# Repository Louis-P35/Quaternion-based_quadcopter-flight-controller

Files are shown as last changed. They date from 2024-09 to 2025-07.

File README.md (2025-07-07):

# MicroFlight - a quadcopter drone flight controller

## Overview

This repository contains the source code for a quadcopter drone flight controller developed in C++ on an STM32H7 microcontroller. Various sensors and control algorithms are used to achieve stable and responsive flight.

## Demo
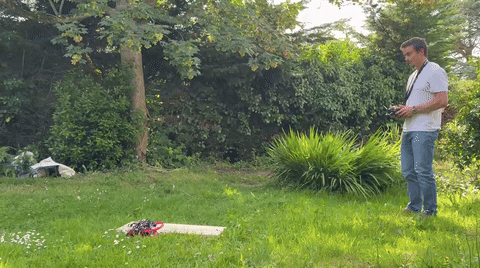
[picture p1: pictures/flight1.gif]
First flight


## Features

- **Microcontroller**: Support the STM32H7 microcontroler, running at 480 MHz.
- **High frequency loop**: IMU data acquisition and filtering at 4khz, PID rate running at 2khz.
- **IMU Sensor**: Support the ICM20948  (3-axis accelerometer, 3-axis gyroscope, and 3-axis magnetometer) IMU with SPI for fast communication.
- **Optical Flow & Lidar**: Support the MTF-01 sensor, it provide horizontal velocity and ground distance to enable position and altitude holding. Use UART with the DMA for non-blocking reading.
- **Radio Receiver**: Support PWM signals and Sbus protocol. Read the Sbus signal over UART with the DMA for non-blocking reading.
- **ESC Control**: Support 500Hz PWM generation to command the brushless motors' ESCs.
- **AHRS (Attitude Estimation)**: Use a Madgwick filter (sensor fusion) for stabilized flight mode.
- **Quaternion Calculations**: To avoid gimbal lock pitfall and enable efficient spherical rotation interpolation, quaternions are used in the entire control loop.
- **PID Controllers**: 3 PID controllers can be chained for various flight modes including stabilized, acrobatic, and position hold mode. PID coefficients can be tuned.
- **Filtering**: First order and second order low pass filter are used to filter out the noise. Cutoff frequencys can be tuned.
- **Blackbox**: Data logging asynchronousely (over UART), data logging on SD card comming soon.
- **Battery Voltage Compensation**: The motors power is constently ajusted according to the battery level. Avoiding to loose thrust at low battery.

Coming soon:
- **CLI**: Command line interface to tune radio input, PID coefficient and filters.
- **Crash Recovery**: Freefal detection and recover from it.
- **FFT and Notch filters**: Run a FFT in real time to detect noise frequency and precisely cut it with Notch filters.

## Architecture Diagram

Click on it to open it on fullscreen
<a href="docs/DroneArchitectureDiagram.drawio.svg?raw=true" target="_blank">
  Diagram overview
</a>

## Quaternions

Quaternions are used through the entire control loop.
Quaternions avoid singularities (like gimbal lock) that can occur with Euler angles, making them a robust choice for representing 3D rotations, especially in drones that can maneuver aggressively.

## AHRS (Attitude and Heading Reference System)

The AHRS fuses data from the accelerometer and gyroscope using a Madgwick filter to estimate the attitude of the quadcopter.
Madgwick filter is fast (use a gradient descent algorithm) and directly output a quaternion.

## PID Control

The project utilizes chained PID controllers to manage motor power in different flight modes.

- **Stabilized Mode**:
  - **Two Cascaded PIDs for Attitude Control**:
    - Attitude setpoint -> [PID Attitude] -> Rate setpoint -> [PID Rate] -> Torque vector -> [Mixer]
    - The attitude error is processed by a PID controller to produce an angular rate target. This target is then used as the input for another PID controller, which compute the torque vector.

- **Acrobatic Mode**:
  - **Single PID for Rate Control**:
    - Rate setpoint -> [PID Rate] -> Torque vector -> [Mixer]
    - The angular rate error is processed by a PID controller to directly compute the torque vector.

- **Position Hold Mode**:
  - **Three Cascaded PIDs for Position Control**:
    - Position Setpoint -> [PID Position] -> Attitude setpoint -> [PID Attitude] -> Rate setpoint -> [PID Rate] -> Torque vector -> [Mixer]
    - The position error is processed by a PID controller to produce an attitude target. Then the attitude error is processed by a PID controller to produce an angular rate target. Finally this rate target is used as the input for rate PID controller, which compute the torque vector.

## Mixer

The mixer is responsible for translating the desired thrust and torque commands into individual motor power levels. This is achieved through a linear transformation that accounts for the drone's geometry and motor configuration.

### X-Configuration Mixing
In the X-quad configuration, the mixer computes the motor outputs based on a target thrust (T) and torques around the three body axes (tx, ty, tz).

### Voltage Compensation
Motor commands are adjusted based on the battery voltage to maintain consistent thrust even as the battery discharges. Since thrust is proportional to the square of the voltage, a quadratic compensation is applied. A low-pass filter smooths the ADC readings to avoid abrupt changes.

### Clamping and Rescaling
To ensure motor outputs remain within the valid range [0, 1000], the mixer applies a rescaling procedure. If any motor command falls outside this range, all outputs are linearly scaled to preserve the relative distribution while ensuring no negative or overdriven values.
This ensures the drone maintains maneuverability even when operating at or near full throttle, by preserving control authority through motor power rescaling.

## Finite State Machines
- This section's documentation is work in progress

## Filtering
Filtering noise is a crucial part of a flight controler. Motors and propellers generates a lot of vibrations that propagate to the IMU that is highly sensitive to it. Silent blocks help mechanicaly reduce it but a proper filtering is still mandatory.
The graph below show the raw gyroscope data (blue line) of the pitch axis with the motors running at around 40% of their power, and the filtered data (orange line).
The filter is a second order low pass filter (biquad Butterworth) with a 75Hz cutoff frequency. 
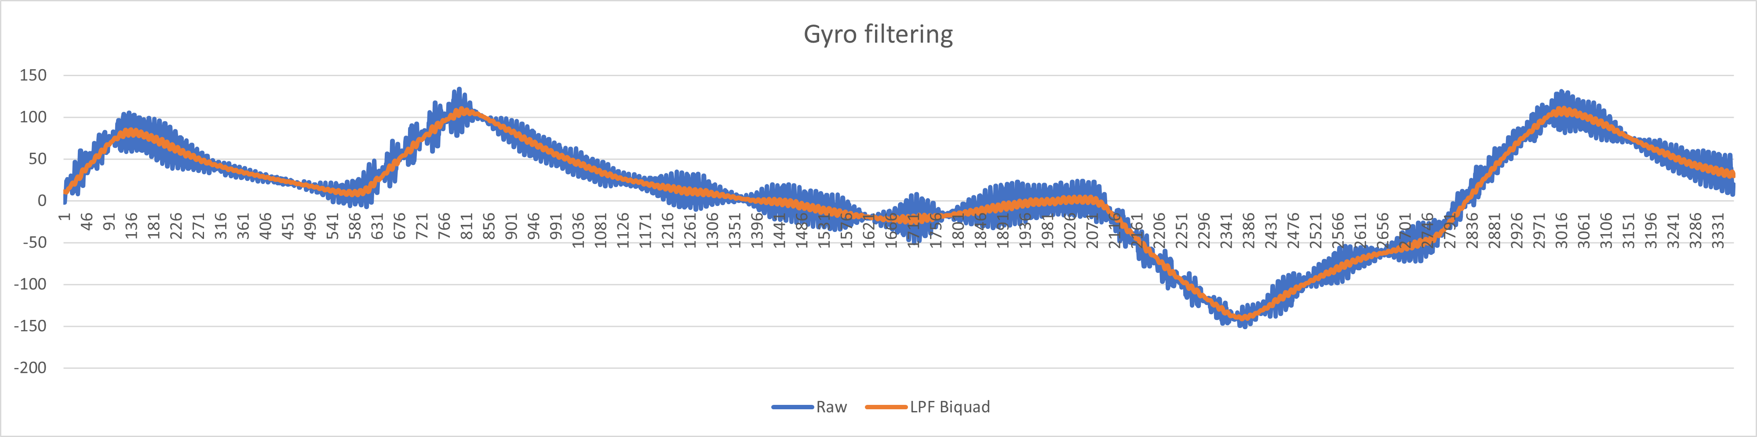
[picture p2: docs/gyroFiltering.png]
Gyro signal


The two graphs below are the fast Fourier transform (FFT) of the gyroscope data of the pitch axis with the motors at 40% of power. On the left the FFT of the raw unfiltered data is shown, on the right the FFT of the filtered data.
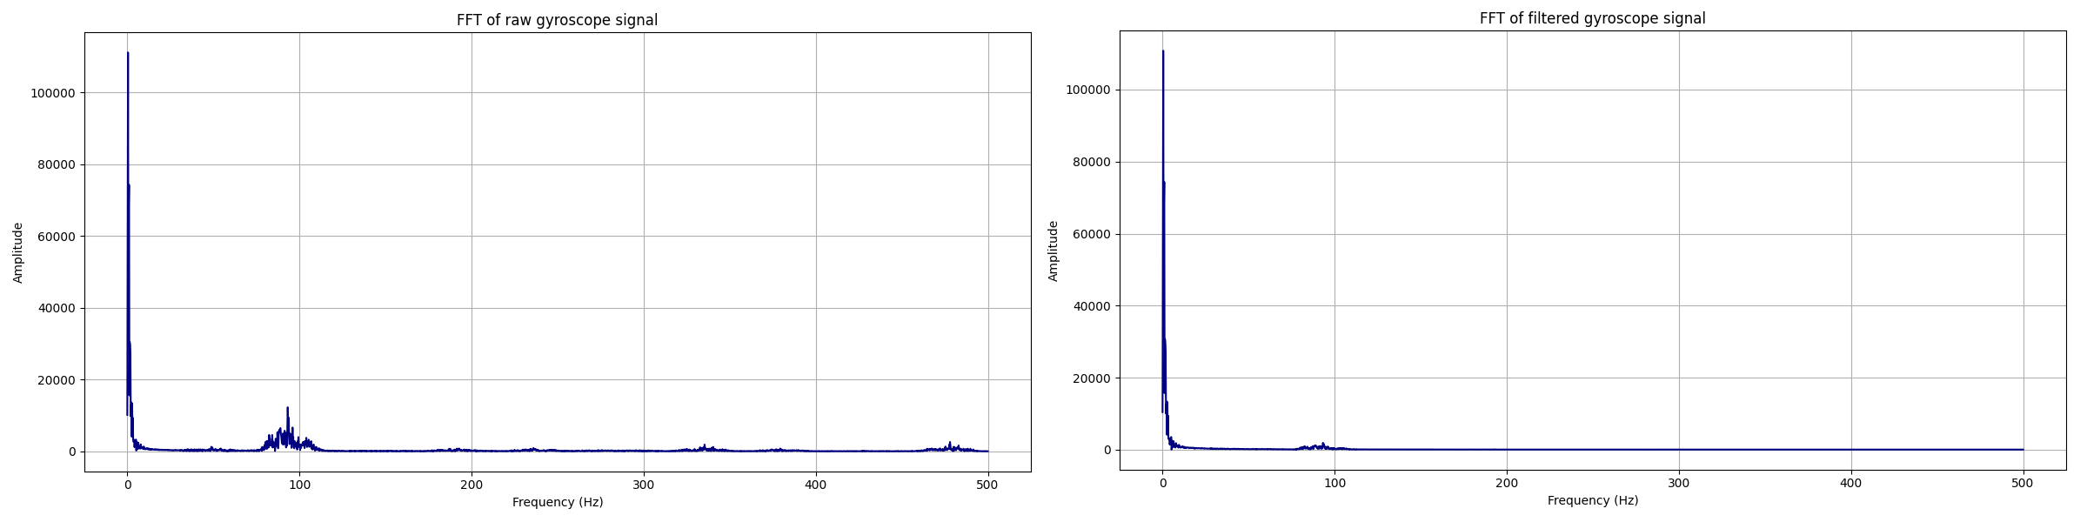
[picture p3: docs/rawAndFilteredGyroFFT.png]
FFT Of Gyro signal

The big spike at 0-20 Hz is due to the drone's movement. The spikes at around 100Hz and beyond are noise and its harmonics. The second order low pass filter show a huge effect at reducing the noise.

## Optical Flow & Lidar sensor (MTF-01)
The MTF-01 optical flow & lidar sensor can use differents comunication protocols (over UART), this software (MicroFlight) handle the Mavlink protocole.
Thus, it must be configured as follow:
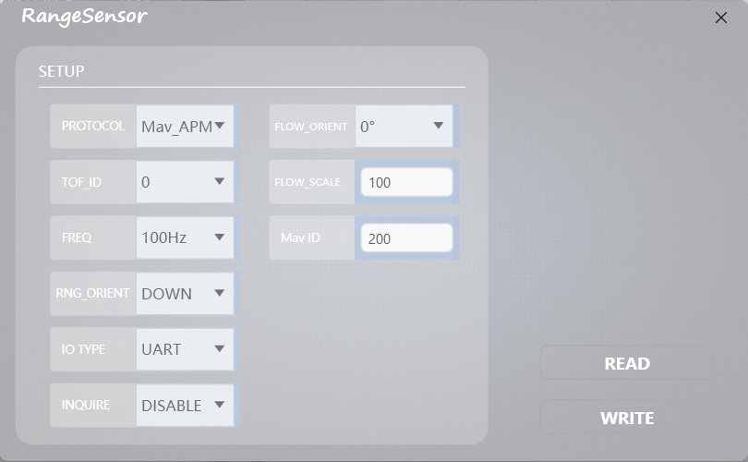
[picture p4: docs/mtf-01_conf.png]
MTF-01 conf

To do this, use the MicroAssistant tool form https://github.com/micoair/MTF-01_USER_MANUAL

The data (flow X/Y & height) are read at 100Hz over UART (Mavlink protocole) using the DMA. This way it does not block the high frequency loop.

## Hardware

- **Frame**: The frame is 3D printed using PLA, which offers significant rigidity. This rigidity is particularly beneficial in dampening low-frequency vibrations generated by the motors, allowing only high-frequency vibrations to pass through. The electronic components, including a highly sensitive accelerometer, are mounted using silent blocks. These silent blocks are effective in reducing high-frequency vibrations, ensuring that the accelerometer and other electronics remain stable and less affected by vibrations.

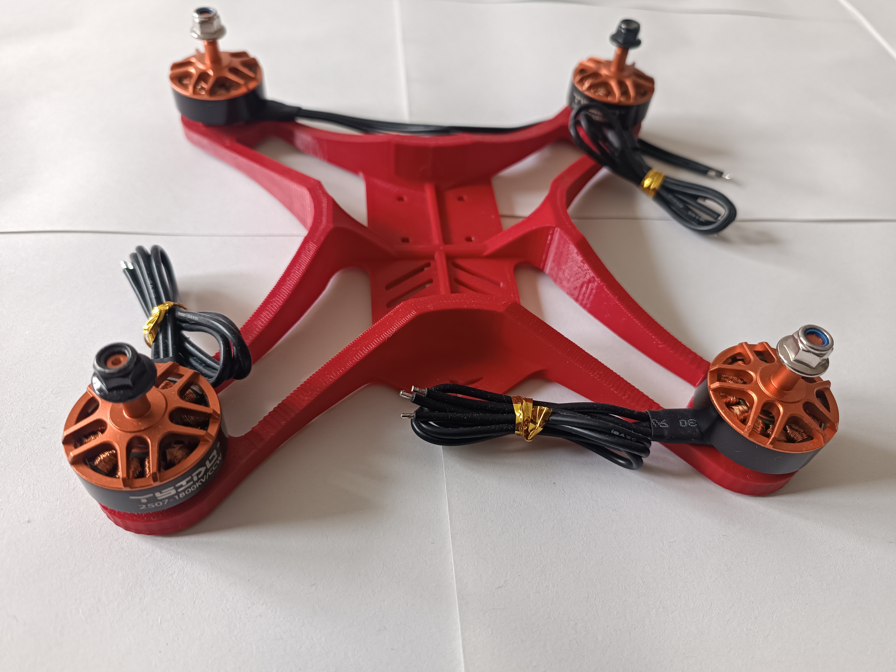
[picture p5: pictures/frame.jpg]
PLA Frame


- **PCB**: A custom PCB board is made to best fit in the chassis. The IMU is solder on this PCB that plugged as a shield on the microcontroller development board.

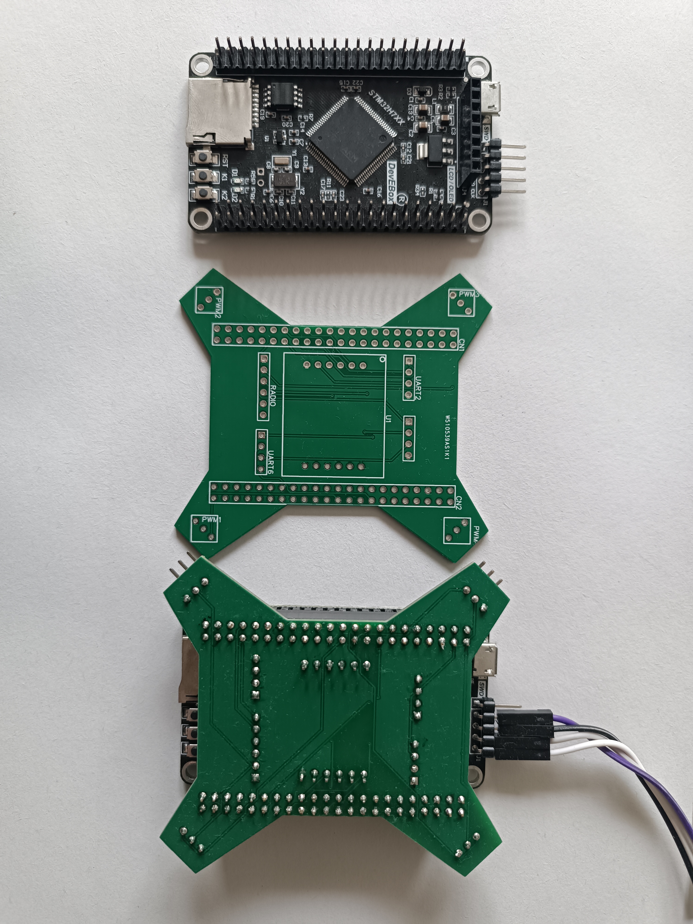
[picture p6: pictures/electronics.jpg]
Electronics


- **MTF-01**: The Optical Flow & Lidar sensor (MTF-01), below the drone, facing the ground.

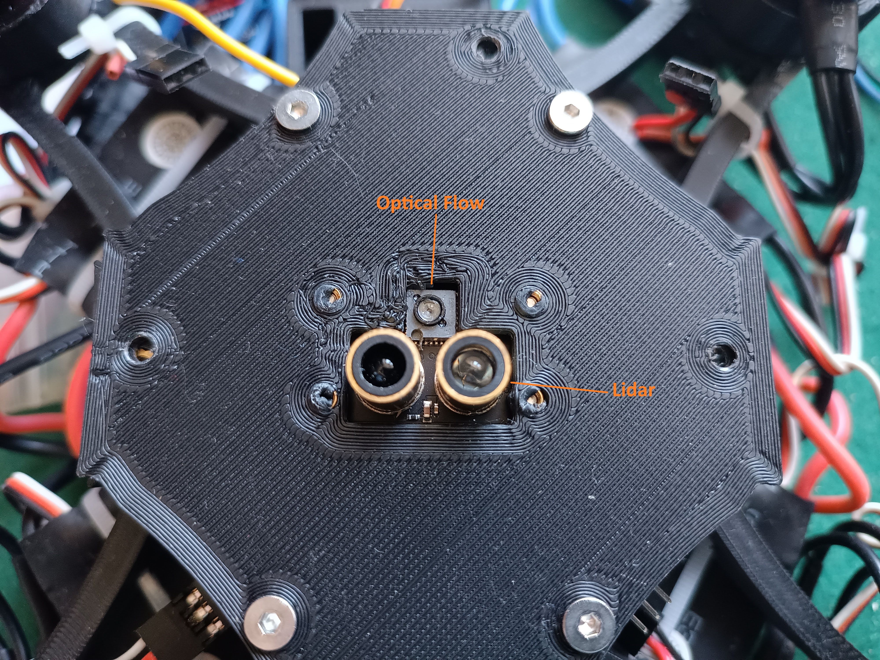
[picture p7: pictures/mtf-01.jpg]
MTF-01


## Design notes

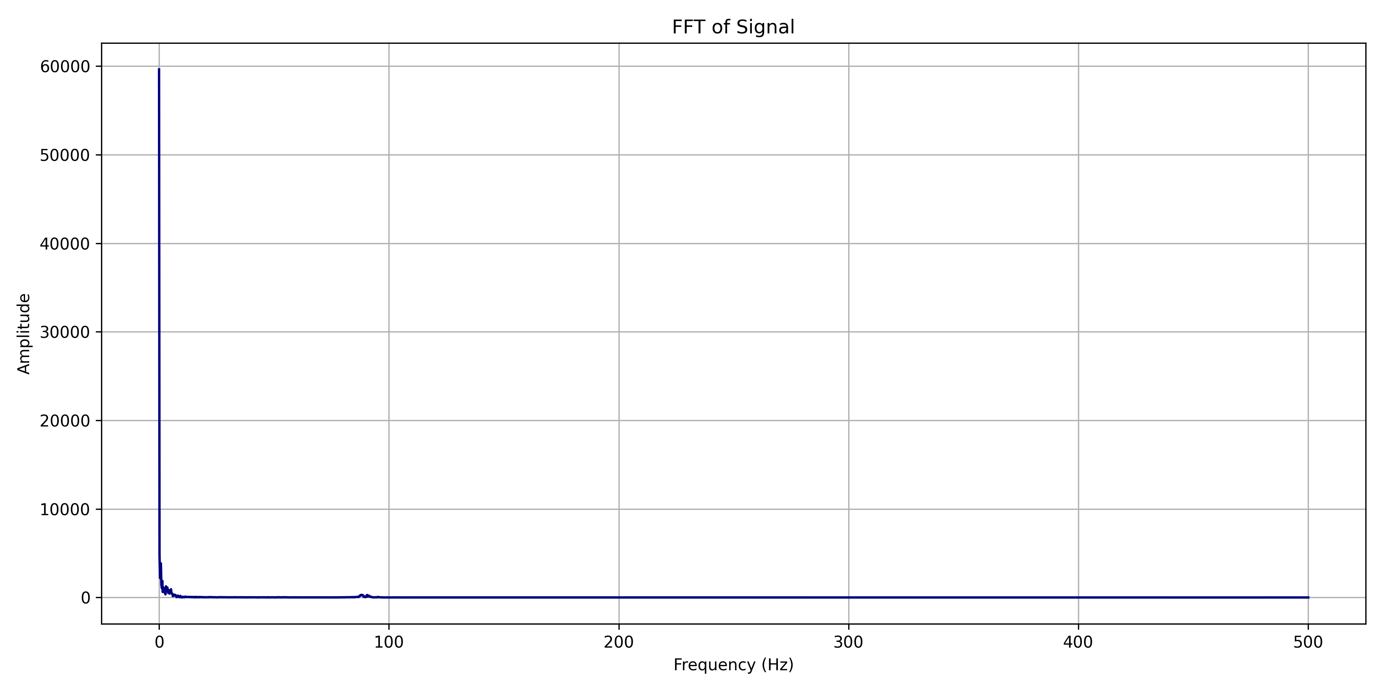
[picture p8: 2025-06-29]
docs/trash/fft_output_filtered_motor_40Percent.png

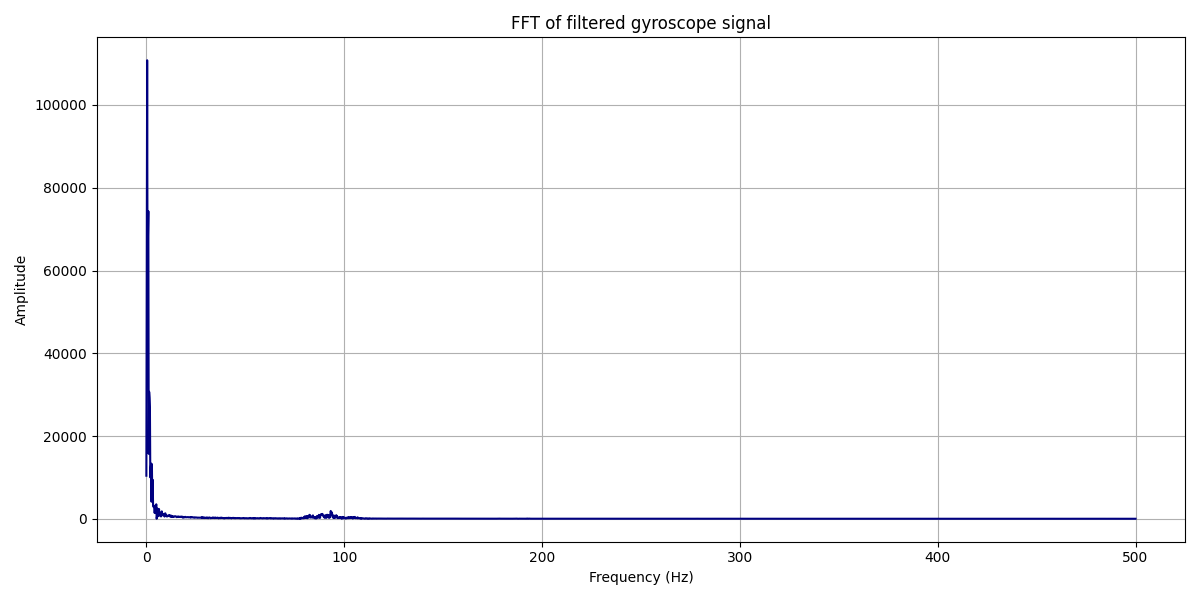
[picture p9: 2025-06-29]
docs/signalFilteredFFT.png

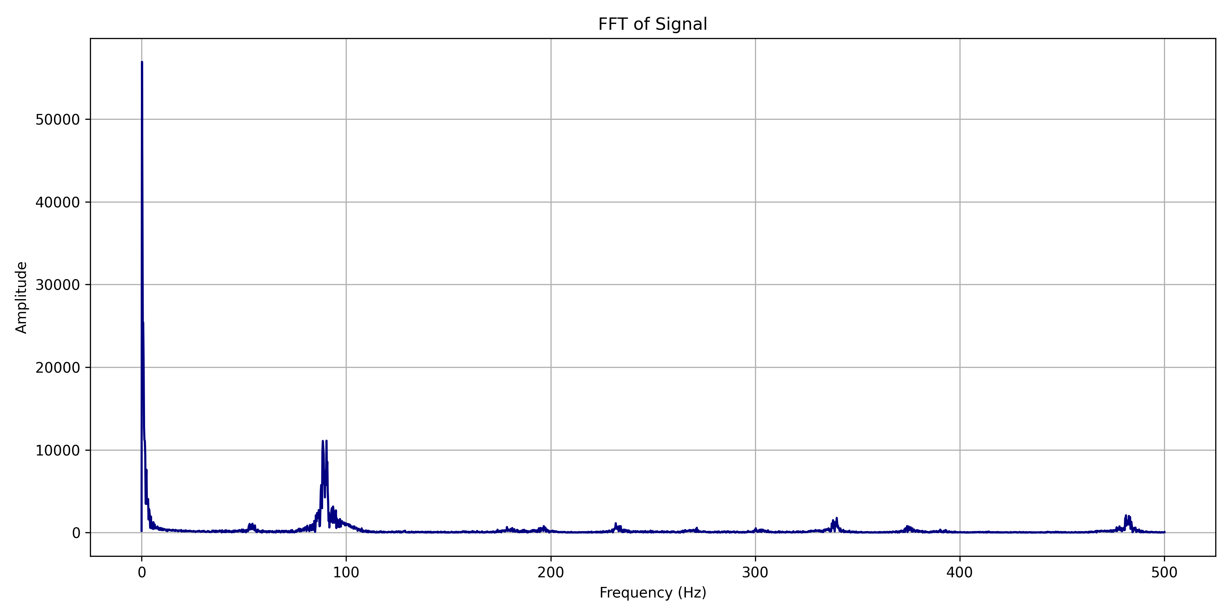
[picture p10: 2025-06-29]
docs/trash/fft_output_raw_motor_40Percent.png

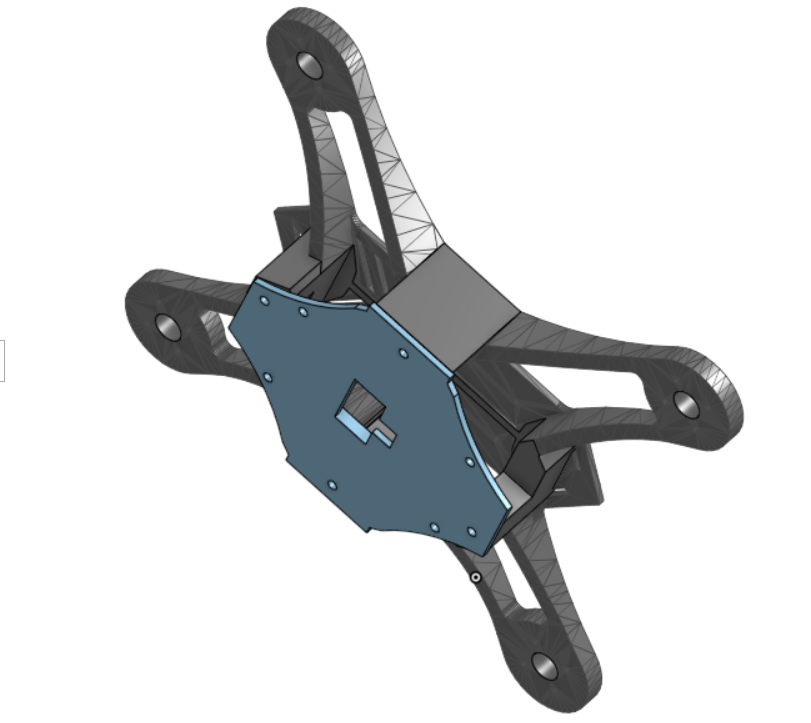
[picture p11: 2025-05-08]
pictures/screen1.png

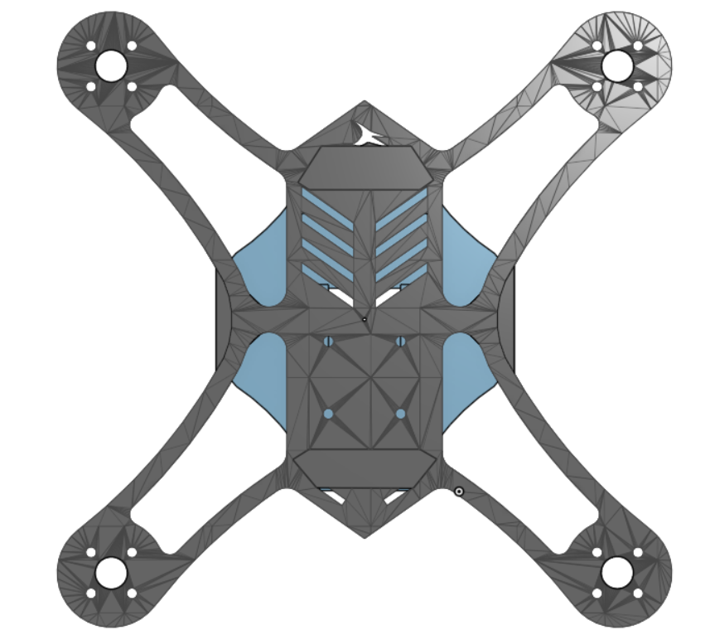
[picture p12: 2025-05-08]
pictures/screen2.png

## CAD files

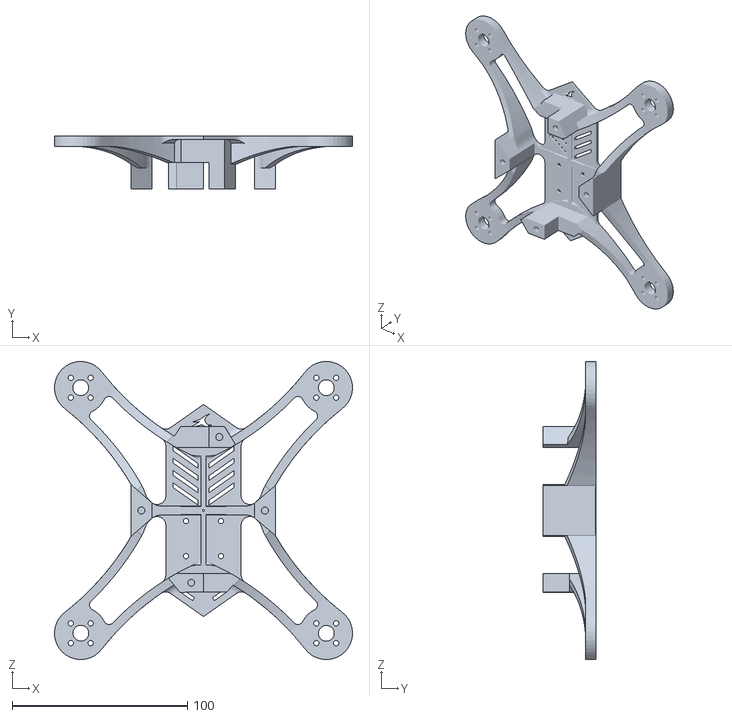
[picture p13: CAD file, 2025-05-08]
3d_models/mainFrame.stl
169.9 x 30.0 x 169.9

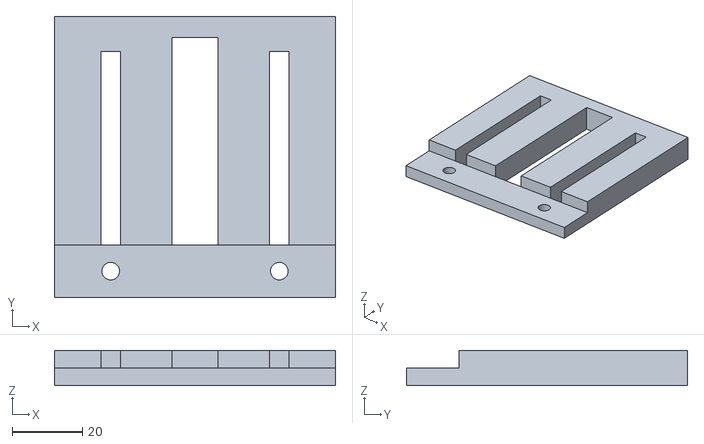
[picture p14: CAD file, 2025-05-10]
3d_models/Gimbal/pitchFrameGravityCenterExtension.stl
80.0 x 80.0 x 10.0

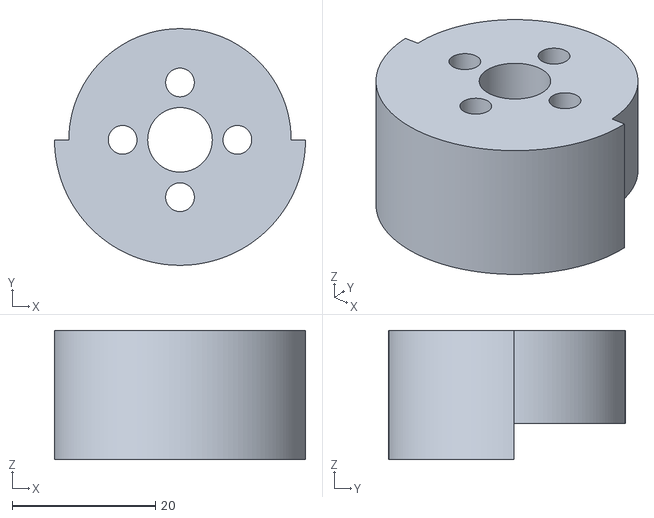
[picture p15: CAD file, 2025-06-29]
3d_models/motorSpacer.stl
35.0 x 33.0 x 18.0

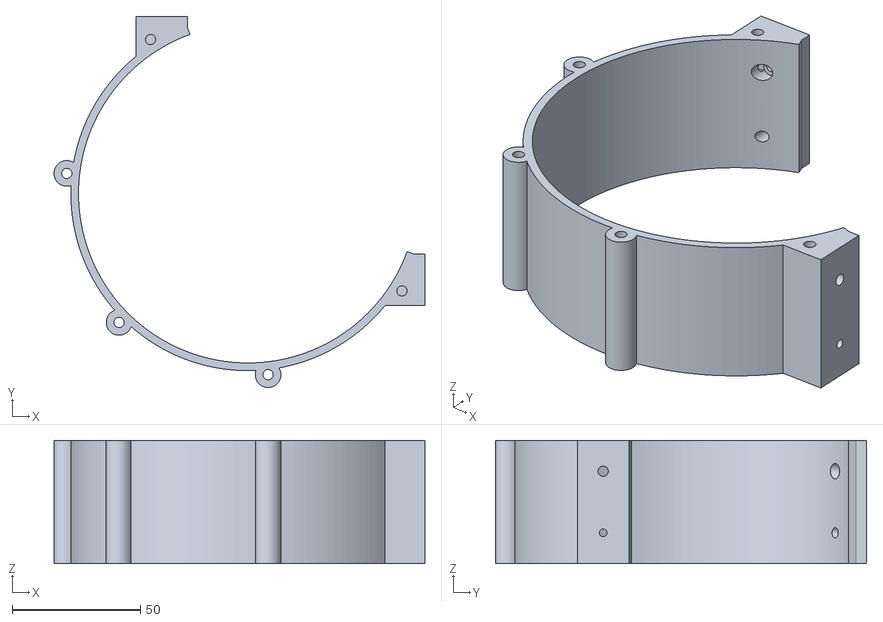
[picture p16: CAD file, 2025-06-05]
3d_models/Cover2.stl
144.6 x 144.6 x 48.0

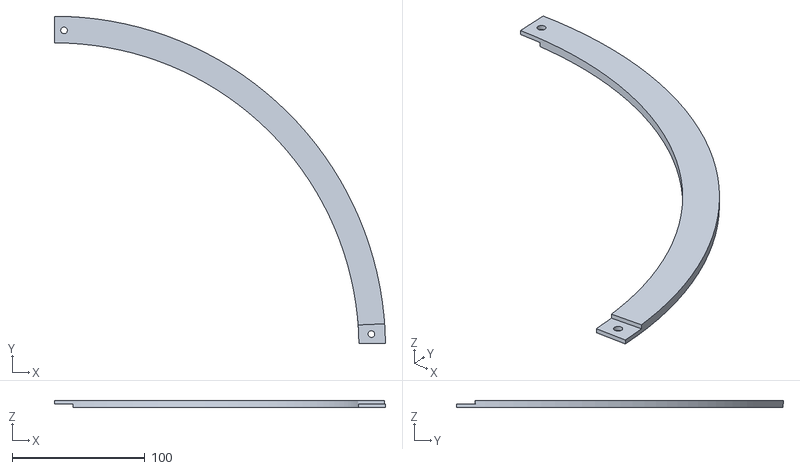
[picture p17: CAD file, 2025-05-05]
3d_models/Gimbal/rollFrame.stl
249.0 x 246.3 x 5.00

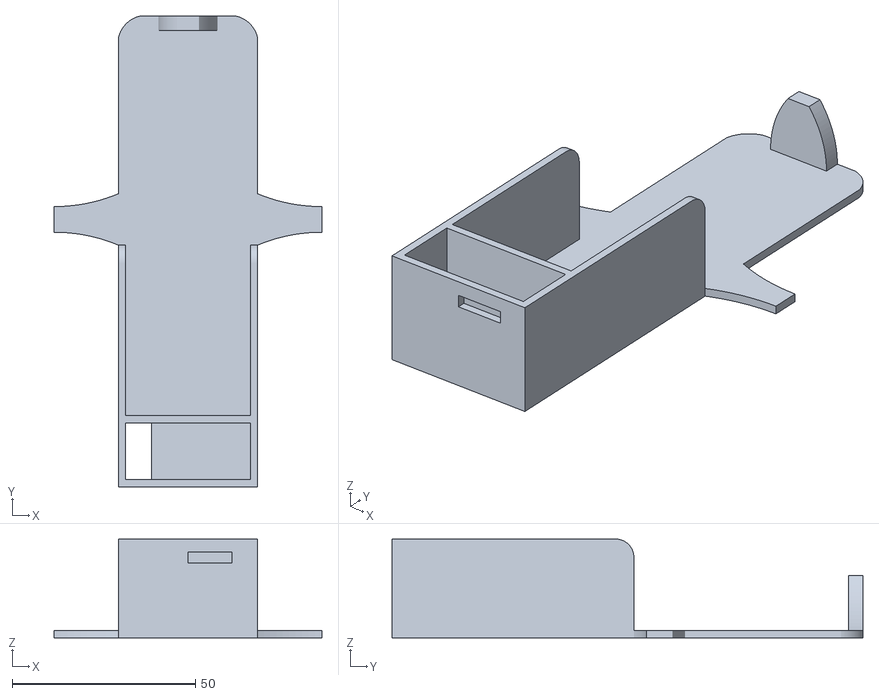
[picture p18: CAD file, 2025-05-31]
3d_models/batterySupport.stl
73.0 x 128.5 x 27.0

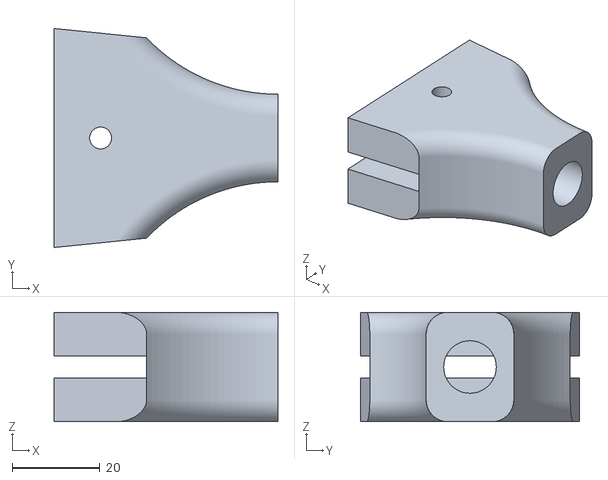
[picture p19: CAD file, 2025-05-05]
3d_models/Gimbal/axesMountRoll.stl
51.1 x 50.0 x 25.0

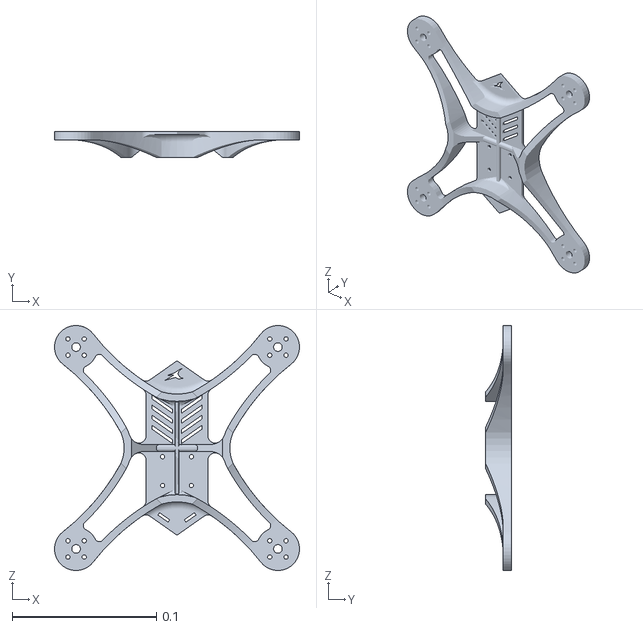
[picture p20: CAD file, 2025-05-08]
3d_models/Frame.STL
0.17 x 0.018 x 0.17

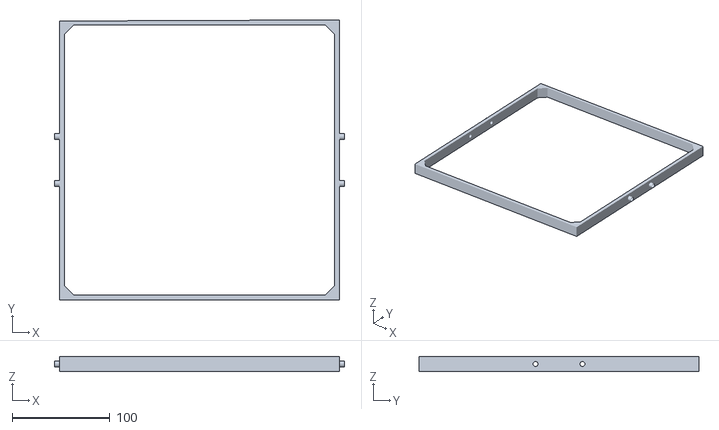
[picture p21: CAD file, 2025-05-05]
3d_models/Gimbal/pitchFrame.stl
297.0 x 287.0 x 15.0

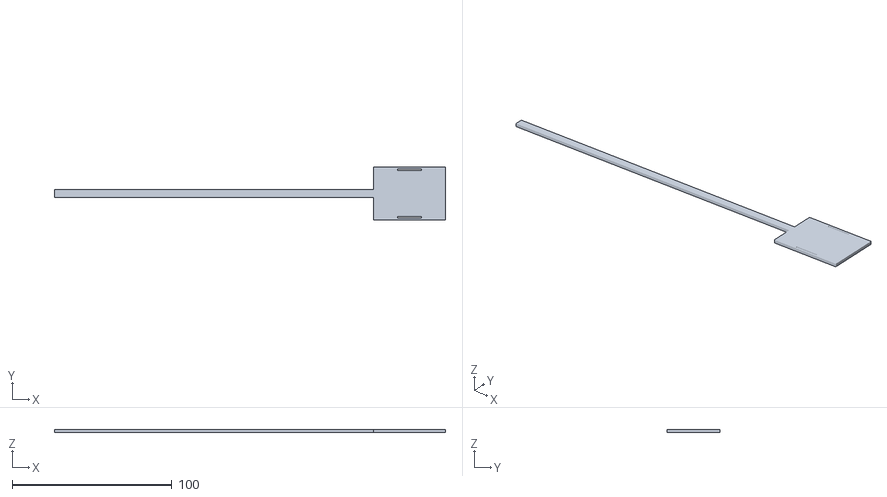
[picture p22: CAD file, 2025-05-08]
3d_models/antennaMount.stl
245.0 x 33.0 x 2.00

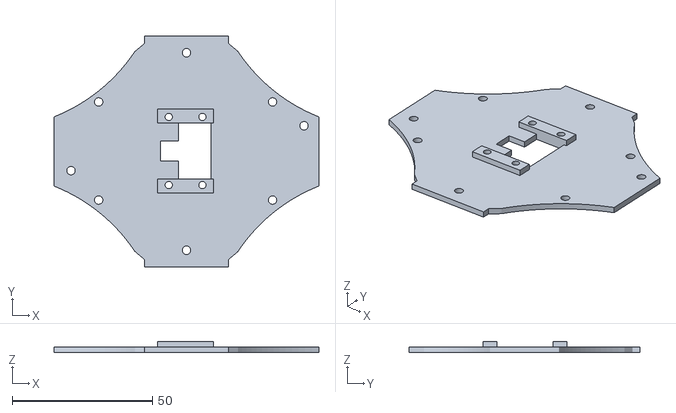
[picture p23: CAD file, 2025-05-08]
3d_models/electronic_mounting_plate.stl
94.5 x 82.4 x 4.00

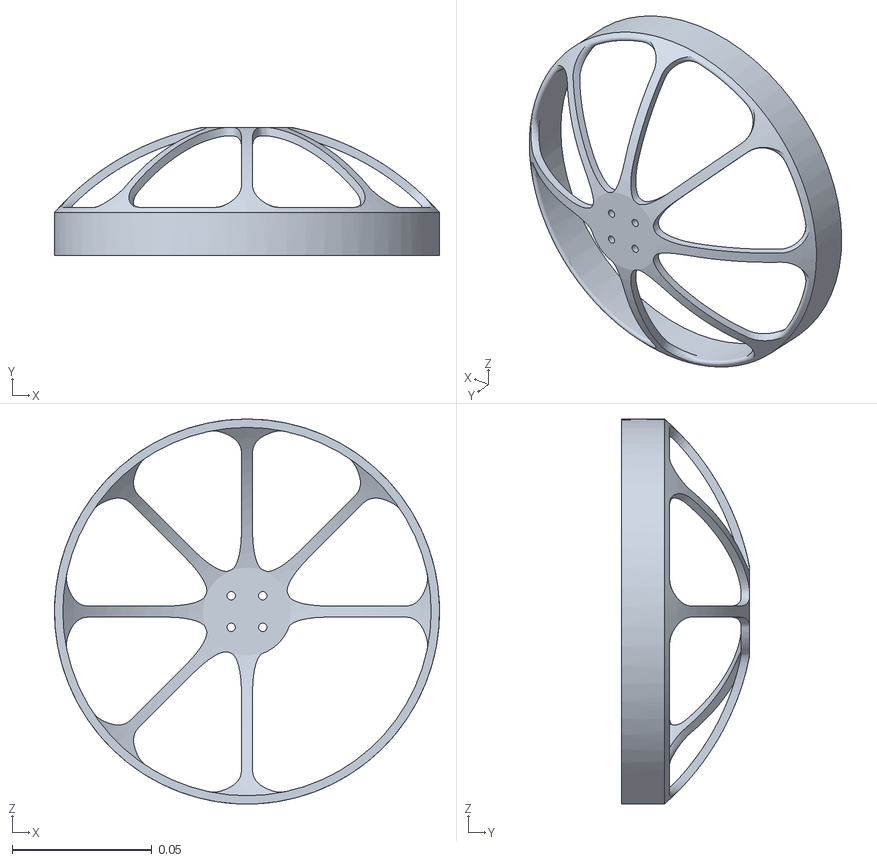
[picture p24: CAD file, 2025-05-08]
3d_models/Cover.STL
0.138 x 0.046 x 0.138

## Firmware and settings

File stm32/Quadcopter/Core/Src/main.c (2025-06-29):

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
/* Includes ------------------------------------------------------------------*/
#include "main.h"

/* USER CODE BEGIN Includes */
#include "Radio/sbusWrapperC.h"
#include "Sensors/mtf01WrapperC.h"
/* USER CODE END Includes */

ADC_HandleTypeDef hadc3;

SPI_HandleTypeDef hspi1;

TIM_HandleTypeDef htim1;
TIM_HandleTypeDef htim2;

UART_HandleTypeDef huart4;
UART_HandleTypeDef huart2;
UART_HandleTypeDef huart6;
DMA_HandleTypeDef hdma_uart4_rx;
DMA_HandleTypeDef hdma_usart2_tx;
DMA_HandleTypeDef hdma_usart6_rx;

/* USER CODE BEGIN PV */

extern uint8_t sbusBuf[];
extern uint8_t mtf01Buf[];

volatile uint8_t rxByteMtf01 = 0;

/* USER CODE END PV */

void SystemClock_Config(void);
void PeriphCommonClock_Config(void);
static void MPU_Config(void);
static void MX_GPIO_Init(void);
static void MX_DMA_Init(void);
static void MX_SPI1_Init(void);
static void MX_USART2_UART_Init(void);
static void MX_TIM1_Init(void);
static void MX_TIM2_Init(void);
static void MX_USART6_UART_Init(void);
static void MX_ADC3_Init(void);
static void MX_UART4_Init(void);
/* USER CODE BEGIN PFP */
extern void interfaceMain();
/* USER CODE END PFP */

/**
  * @brief  The application entry point.
  * @retval int
  */
int main(void)
{

  /* MPU Configuration--------------------------------------------------------*/
  MPU_Config();

  /* MCU Configuration--------------------------------------------------------*/

  /* Reset of all peripherals, Initializes the Flash interface and the Systick. */
  HAL_Init();

  /* Configure the system clock */
  SystemClock_Config();

  /* Configure the peripherals common clocks */
  PeriphCommonClock_Config();

  /* Initialize all configured peripherals */
  MX_GPIO_Init();
  MX_DMA_Init();
  MX_SPI1_Init();
  MX_USART2_UART_Init();
  MX_TIM1_Init();
  MX_TIM2_Init();
  MX_USART6_UART_Init();
  MX_ADC3_Init();
  MX_UART4_Init();
  /* USER CODE BEGIN 2 */

	// Clear any pending IDLE flag
	__HAL_UART_CLEAR_IDLEFLAG(&huart6);
	// Kick off the circular DMA transfer into the 25-byte buffer
	HAL_UART_Receive_DMA(&huart6, sbusBuf, SBUS_FRAME_SIZE);
	// Enable the UART IDLE interrupt so we know when a full frame has arrived
	__HAL_UART_ENABLE_IT(&huart6, UART_IT_IDLE);


	// Clear any pending IDLE flag
	__HAL_UART_CLEAR_IDLEFLAG(&huart4);
	// Kick off the circular DMA transfer into the buffer
	HAL_UART_Receive_DMA(&huart4, mtf01Buf, MTF01_FRAME_SIZE);
	// Enable the UART IDLE interrupt so we know when a full frame has arrived
	__HAL_UART_ENABLE_IT(&huart4, UART_IT_IDLE);

  // Start timer 2
  HAL_TIM_Base_Start_IT(&htim2);

  // Init PWMs
  HAL_TIM_PWM_Start(&htim1, TIM_CHANNEL_1);
  HAL_TIM_PWM_Start(&htim1, TIM_CHANNEL_2);
  HAL_TIM_PWM_Start(&htim1, TIM_CHANNEL_3);
  HAL_TIM_PWM_Start(&htim1, TIM_CHANNEL_4);

  // Main loop here
  interfaceMain();

  /* USER CODE END 2 */

  /* Infinite loop */
  /* USER CODE BEGIN WHILE */
  while (1)
  {
    /* USER CODE END WHILE */

    /* USER CODE BEGIN 3 */
  }
  /* USER CODE END 3 */
}

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
 /* MPU Configuration */

void MPU_Config(void)
{
  MPU_Region_InitTypeDef MPU_InitStruct = {0};

  /* Disables the MPU */
  HAL_MPU_Disable();

  /** Initializes and configures the Region and the memory to be protected
  */
  MPU_InitStruct.Enable = MPU_REGION_ENABLE;
  MPU_InitStruct.Number = MPU_REGION_NUMBER0;
  MPU_InitStruct.BaseAddress = 0x0;
  MPU_InitStruct.Size = MPU_REGION_SIZE_4GB;
  MPU_InitStruct.SubRegionDisable = 0x87;
  MPU_InitStruct.TypeExtField = MPU_TEX_LEVEL0;
  MPU_InitStruct.AccessPermission = MPU_REGION_NO_ACCESS;
  MPU_InitStruct.DisableExec = MPU_INSTRUCTION_ACCESS_DISABLE;
  MPU_InitStruct.IsShareable = MPU_ACCESS_SHAREABLE;
  MPU_InitStruct.IsCacheable = MPU_ACCESS_NOT_CACHEABLE;
  MPU_InitStruct.IsBufferable = MPU_ACCESS_NOT_BUFFERABLE;

  HAL_MPU_ConfigRegion(&MPU_InitStruct);
  /* Enables the MPU */
  HAL_MPU_Enable(MPU_PRIVILEGED_DEFAULT);

}

/**
  * @brief  This function is executed in case of error occurrence.
  * @retval None
  */
void Error_Handler(void)
{
  /* USER CODE BEGIN Error_Handler_Debug */
  /* User can add his own implementation to report the HAL error return state */
  __disable_irq();
  while (1)
  {
  }
  /* USER CODE END Error_Handler_Debug */
}

#ifdef  USE_FULL_ASSERT
/**
  * @brief  Reports the name of the source file and the source line number
  *         where the assert_param error has occurred.
  * @param  file: pointer to the source file name
  * @param  line: assert_param error line source number
  * @retval None
  */
void assert_failed(uint8_t *file, uint32_t line)
{
  /* USER CODE BEGIN 6 */
  /* User can add his own implementation to report the file name and line number,
     ex: printf("Wrong parameters value: file %s on line %d\r\n", file, line) */
  /* USER CODE END 6 */
}
#endif /* USE_FULL_ASSERT */

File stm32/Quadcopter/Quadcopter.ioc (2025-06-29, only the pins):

Mcu.UserName=STM32H743VITx
PA0.GPIO_Label=MTF-01_TX
PA0.Signal=UART4_TX
PA1.GPIO_Label=MTF-01_RX
PA1.Signal=UART4_RX
PA10.Signal=S_TIM1_CH3
PA11.Signal=S_TIM1_CH4
PA2.Signal=USART2_TX
PA3.Signal=USART2_RX
PA4.GPIO_Label=SPI_CS
PA4.Signal=GPIO_Output
PA5.Signal=SPI1_SCK
PA6.Signal=SPI1_MISO
PA7.Signal=SPI1_MOSI
PA8.Signal=S_TIM1_CH1
PA9.Signal=S_TIM1_CH2
PB0.Signal=GPXTI0
PB1.Signal=GPXTI1
PB5.Signal=GPXTI5
PC3_C.Signal=ADC3_INP1
PC6.GPIO_Label=SBUS_TX
PC6.Signal=USART6_TX
PC7.GPIO_Label=SBUS_RX
PC7.Signal=USART6_RX

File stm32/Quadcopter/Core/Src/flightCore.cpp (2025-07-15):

/*
 * flightCore.cpp
 *
 *  Created on: Jul 10, 2025
 *      Author: louis
 */


// Includes from project
#include "flightCore.hpp"
#include "Scheduler/scheduler.hpp"
#include "logManager.hpp"
#include "PID/controlStrategy.hpp"
#include "PID/pid.hpp"
#include "Radio/radio.hpp"
#include "FSM/stateMachine.hpp"

#ifndef DISABLE_UNIT_TESTING
#include "UnitTests/schedulerUnitTests.hpp"
#endif

// Includes from STL
#include <algorithm>


#define DEGREE_TO_RAD (M_PI/180.0)
#define RAD_TO_DEG (180.0/M_PI)


/*
 * PIDs coeff
 */

#define SATURATION (75.0f)
#define MAX_OUT (1000.0f)
#define MIN_OUT (-1000.0f)

#define ROLL_PITCH_RATE_MAX_D_PERCENT (0.75f) // < 1 for stability, [1, 2] for aggresivity

// Attitude loop PIDs coefficients
#define ROLLPITCH_ANGLE_KP (8.0f)
#define ROLLPITCH_ANGLE_KI (0.0f)
#define ROLLPITCH_ANGLE_KD (0.0f)

#define YAW_ANGLE_KP (ROLLPITCH_ANGLE_KP / 2.0f)
#define YAW_ANGLE_KI (0.0f)
#define YAW_ANGLE_KD (0.0f)

// Rate loop PIDs coefficients
#define ROLLPITCH_RATE_KP (0.4f)
#define ROLLPITCH_RATE_KI (0.4f)
#define ROLLPITCH_RATE_KD (0.04f)

#define YAW_RATE_KP (0.3f)
#define YAW_RATE_KI (0.01f)
#define YAW_RATE_KD (0.0f)

// Position loop PIDs coefficients
#define ROLLPITCH_POS_KP (0.0f)
#define ROLLPITCH_POS_KI (0.0f)
#define ROLLPITCH_POS_KD (0.0f)

#define YAW_POS_KP (0.0f)
#define YAW_POS_KI (0.0f)
#define YAW_POS_KD (0.0f)

// Radio control
#define THROTTLE_HOVER_OFFSET (0.1f) // Around hover point
#define THROTTLE_EXPO (0.99f)
#define TARGET_ANGLE_MAX (45.0f)
#define TARGET_RATE_MAX (200.0f)
#define THRUST_IS_FLYING_THRESHOLD_UP (340.0f)
#define THRUST_IS_FLYING_THRESHOLD_DOWN (250.0f)


extern TIM_HandleTypeDef htim1;
extern SPI_HandleTypeDef hspi1;
extern UART_HandleTypeDef huart6;
extern DMA_HandleTypeDef hdma_usart6_rx;
extern ADC_HandleTypeDef hadc3;


extern Scheduler g_scheduler;
extern FlightCore* g_pFlightCore;


volatile bool g_enableRadioLoop = false;
volatile bool g_start = false;

volatile bool g_startRecord = false;
volatile bool g_startPrint = false;

//#define CALIBRATE_IMU (1)

// 0.45 (x4) = take off thrust

//#define COMPUTE_HOVER_OFFSET (1)

// Uncomment this to disable motors
#define DEBUG_DISABLE_MOTORS (1)
//#define PID_TESTING_MODE (1)





// TODOs:
// GYRO à 6khz => voir ce que ça donne de monter les fréquences de coupure des 2 LPF (moins de latences)
// 		=> Test avec un biquad Butterworth 2ᵉ ordre à la place des 2 LPF chainé (moins de latences)

// PID d terme chainer 2 LPF et monter la fréquence de coupure (moins de latence)

// PID D terd on derived gyro instead of derived error
// Compute frequency and do not /dt in pid
// Set PID coefs at hover point
// Set hover thrust offset precisely
// Remove Eigen
// Keep yaw in rates
// Compute target quaternion only in STAB/HORIZON(& stick 0) mode



FlightCore::FlightCore(uint16_t spi_cs_pin, GPIO_TypeDef* spi_cs_gpio_port) :
		m_radio(THROTTLE_HOVER_OFFSET, THROTTLE_EXPO, TARGET_ANGLE_MAX, TARGET_RATE_MAX)
{

}


/*
 * Called once at the beginning of the software.
 */
void FlightCore::mainSetup()
{
	constexpr float pidAngleOutputCutOffFreq = 15.0f;

	// Setup the serial print
	LogManager::getInstance().setup();

	// Setup the IMU (ICM20948)
	m_imu.init(4000.0f); // TODO hardcoded...

	// Init AHRS
	m_madgwickFilter = MadgwickFilter<float>();

	// Calibrate IMU
#ifdef CALIBRATE_IMU
	m_imu.gyroAccelCalibration();
#else
	m_imu.setGyroOffset(Vector3<float>(0.0010f, -0.0005f, 0.0196f));
	m_imu.setAccelOffset(Vector3<float>(0.0067, 0.0277, -0.0146));
#endif

	// Setup PWM reading for radio receiver
	setupRadio();

	// Setup optical flow sensor
	mtf01WrapperSetInstance(static_cast<void*>(&m_opticalflow));

	// Set Startup state
	MainStateMachine::getInstance().setState(MainStateMachine::getInstance().getStartupSequenceState());

	// Configure PIDs
	m_ctrlStrat.setRatePIDderivativeMode(DerivativeMode::OnMeasurement);
	m_ctrlStrat.setRatePIDcoefsRoll(ROLLPITCH_RATE_KP, ROLLPITCH_RATE_KI, ROLLPITCH_RATE_KD);
	m_ctrlStrat.setRatePIDcoefsPitch(ROLLPITCH_RATE_KP, ROLLPITCH_RATE_KI, ROLLPITCH_RATE_KD);
	m_ctrlStrat.setRatePIDcoefsYaw(YAW_RATE_KP, YAW_RATE_KI, YAW_RATE_KD);
	m_ctrlStrat.setPIDsatMinMaxRate(SATURATION, MIN_OUT, MAX_OUT, ROLL_PITCH_RATE_MAX_D_PERCENT);

	m_ctrlStrat.setAnglePIDderivativeMode(DerivativeMode::OnError);
	m_ctrlStrat.setAnglePIDcoefsRoll(ROLLPITCH_ANGLE_KP, ROLLPITCH_ANGLE_KI, ROLLPITCH_ANGLE_KD);
	m_ctrlStrat.setAnglePIDcoefsPitch(ROLLPITCH_ANGLE_KP, ROLLPITCH_ANGLE_KI, ROLLPITCH_ANGLE_KD);
	m_ctrlStrat.setAnglePIDcoefsYaw(YAW_ANGLE_KP, YAW_ANGLE_KI, YAW_ANGLE_KD);
	m_ctrlStrat.setPIDsatMinMaxAngle(SATURATION, MIN_OUT, MAX_OUT);

	m_ctrlStrat.setPosPIDderivativeMode(DerivativeMode::OnError);
	m_ctrlStrat.setPosPIDcoefsRoll(ROLLPITCH_POS_KP, ROLLPITCH_POS_KI, ROLLPITCH_POS_KD);
	m_ctrlStrat.setPosPIDcoefsPitch(ROLLPITCH_POS_KP, ROLLPITCH_POS_KI, ROLLPITCH_POS_KD);
	m_ctrlStrat.setPosPIDcoefsYaw(YAW_POS_KP, YAW_POS_KI, YAW_POS_KD);
	m_ctrlStrat.setPIDsatMinMaxPos(SATURATION, MIN_OUT, MAX_OUT);

	// D term filters for PID rate loop
	constexpr float rateLoopFreq = 2000.0f; // TODO hardcoded...
	constexpr float angleLoopFreq = 1000.0f; // TODO hardcoded...
	constexpr float paramsPIDAngleCutOff[1] = {pidAngleOutputCutOffFreq};

	for (size_t i = 0; i < 3; ++i)
	{
		m_ctrlStrat.m_rateLoop[i].m_dTermLpf.init(rateLoopFreq, 10.0f);
		m_ctrlStrat.m_rateLoop[i].m_dTermLpf2.init(rateLoopFreq, 10.0f);
		m_ctrlStrat.m_rateLoop[i].m_ffTermLpf.init(rateLoopFreq, 50.0f);

		m_ctrlStrat.m_angleLoop[i].m_filteredOutput.init(angleLoopFreq, paramsPIDAngleCutOff);
	}

	// Set the control mode
	m_ctrlStrat.m_flightMode = StabilizationMode::STAB;

	// Enable PID angle loop
	// Enable it only in certain flight mode
	if(m_ctrlStrat.m_flightMode == StabilizationMode::STAB ||
			m_ctrlStrat.m_flightMode == StabilizationMode::POSHOLD)
	{
		m_angleLoopEnable = true; // TODO: Need to be done in the state machine
	}

	// Enable PID position hold loop (that will run in the state machine)
	// Enable it only in certain flight mode
	if (g_pFlightCore->m_ctrlStrat.m_flightMode == StabilizationMode::POSHOLD)
	{
		g_pFlightCore->m_posLoopEnable = true; // TODO: Need to be done in the state machine
	}


	// Setup the tasks
	// addAllTasks(g_scheduler); // Unit test

	bool taskAddSuccess = true;

	// 4 KHz tasks
	taskAddSuccess &= g_scheduler.addTask(TaskType::eRead_IMU, 0, readIMU_task, FREQUENCY_SLOT::e_4KHZ);

	// 2 KHz tasks
	taskAddSuccess &= g_scheduler.addTask(TaskType::ePID_rate, 0, pidRate_task, FREQUENCY_SLOT::e_2KHZ);

	// 1 KHz tasks
	taskAddSuccess &= g_scheduler.addTask(TaskType::eAHRS, 0, AHRS_task, FREQUENCY_SLOT::e_1KHZ);
	taskAddSuccess &= g_scheduler.addTask(TaskType::ePID_att, 1, pidAtt_task, FREQUENCY_SLOT::e_1KHZ);

	// 500 Hz tasks
	taskAddSuccess &= g_scheduler.addTask(TaskType::eESCs, 0, ESCs_task, FREQUENCY_SLOT::e_500HZ);
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

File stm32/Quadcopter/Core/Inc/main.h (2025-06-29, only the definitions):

#define MTF_01_TX_Pin GPIO_PIN_0
#define MTF_01_TX_GPIO_Port GPIOA
#define MTF_01_RX_Pin GPIO_PIN_1
#define MTF_01_RX_GPIO_Port GPIOA
#define SPI_CS_Pin GPIO_PIN_4
#define SPI_CS_GPIO_Port GPIOA
#define SBUS_TX_Pin GPIO_PIN_6
#define SBUS_TX_GPIO_Port GPIOC
#define SBUS_RX_Pin GPIO_PIN_7
#define SBUS_RX_GPIO_Port GPIOC

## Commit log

2024-04-08 Add files via upload
    Kalman filter, calibration, refacto
2024-04-24 Debug print & radio test
2024-04-29 Add files via upload
    Quaternion and madgwick filter implementation
2024-05-06 PID calibration, lots of small fix
2024-06-08 Create branch for stm32h7 developpement
2024-06-11 mpu9250 SPI read write
2024-06-23 AHRS complementary filter & PID design pattern
2024-07-06 Fix critical errors, use Eigen everywere & lots of refacto
    [logManager.cpp, pid.hpp, quadcopter.cpp]
2024-07-18 Fix gyro scale bug, fix SPI configuration, EKF working
    [main.cpp, quadcopter.cpp, quadcopter.hpp]
2024-07-31 Mainly ICM20948 IMU
2024-09-01 Remove arduino version
2025-02-15 Fork the kalman filter submodule repo
2025-02-16 Add imu lib submudule
2025-04-12 remove driver from gitignore
2025-04-12 push drivers
2025-04-12 Add icm20948 driver
2025-04-15 Clean print IMU data
2025-04-15 Remove old IMU code
2025-04-21 Add gyro & acc calibration and fix icm20948 lib
    [icm20948.cpp, main.cpp, quadcopter.cpp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]
2025-04-22 Add PWM reading
2025-04-24 Simplify PID control strategies
2025-04-26 Switch to madgwick because of EKF perf issues, add models, refacto PIDs
    [body_extension.stl, electronic_mounting_plate.stl]
2025-04-28 Read radio receiver
    [battery_support.stl]
2025-05-01 Fix radio pwm read bug
    [Quadcopter.ioc, main.cpp, readRadio.cpp]
2025-05-02 PWM working
2025-05-03 Fix thrust vector command
    [main.cpp, quadcopter.cpp, quadcopter.hpp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]
2025-05-03 Add motors mixer
2025-05-04 Add gimbal 3d files
    [pitchFrame.stl, rollFrame.stl]
2025-05-04 Refacto PID chain & Scheduler
2025-05-05 Update gimbzl 3d files & gcodes
    [axesMountRoll.stl, pitchFrame.stl, rollFrame.stl]
2025-05-05 Add IMU hover offset
2025-05-08 Update 3d models
    [Cover.STL, Frame.STL, antennaMount.stl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]
2025-05-08 Propagate PID coeff + propagate gyro rates + fix motors positions + fix bug in mixer
    [motorMixer.cpp, motorMixer.hpp, pid.hpp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]
2025-05-08 Fix enum to real motors mapping & fix yaw direction
    [motorMixer.cpp, scheduler.cpp]
2025-05-08 remove g-code files
    [body_extension.stl]
2025-05-10 refacto + fix remove lpf from broken icm20948 lib + implement software lpf + first PID rates tuning
    [icm20948.cpp, logManager.cpp, motorMixer.cpp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]
2025-05-10 add 3d model to make the gimball balanced
    [pitchFrameGravityCenterExtension.stl]
2025-05-10 fix gyro & accel LPF bug
    [scheduler.cpp]
2025-05-12 Huge refacto double -> float + fixed timer interupt loop for IMU read + PID output (and mixer input) scaled 1000x
    [Quadcopter.ioc, icm20948.cpp, logManager.cpp]
2025-05-13 UART over DMA
2025-05-13 Figure out the filter process to reduce dTerm noise + first PID rate coefs tuning
    [pid.hpp, readRadio.cpp, scheduler.cpp]
2025-05-23 Test filters
2025-05-25 Fix sbus - working now
    [main.c, radio.cpp, radioSbus.cpp]
2025-05-26 Refacto pwm radio
2025-05-26 Voltage compensation + pid rate filter & tuning
2025-05-30 Add ADC for battery level monitoring
2025-05-31 Update battery support 3d file
    [batterySupport.stl, battery_support.stl]
2025-05-31 Read adc
2025-06-01 Quadratic voltage correction & PID coef setting
    [motorMixer.cpp, motorMixer.hpp, scheduler.cpp]
2025-06-03 Update PID rate coeffs
2025-06-05 Add new cover 3d file
    [Cover2.stl]
2025-06-05 Plug PID angle
2025-06-06 Working pitch attitude on test bench
2025-06-06 Fix roll<->yaw invertion
2025-06-07 Accelerometer & gyroscope filtering for AHRS
2025-06-08 Refacto & update FSM class & set coefs PIDs yaw
2025-06-11 Add base class for MTF-01 optical flow & lidar sensor
2025-06-18 Add motor spacer 3d model
    [motorSpacer.stl]
2025-06-20 HAL configuration for MTF-01 reading with Uart4
2025-06-20 Update DMA interrupt preemption priority
2025-06-22 Add filtering in readme
2025-06-23 Read UART for mtf-01
2025-06-24 Read mtf-01 with dma
2025-06-24 Call handleByte from dma interrupt
2025-06-29 Resolve Copilot review comments
    [main.c]
2025-07-12 Fix stack overflow + add unit testing
    [flightCore.cpp, interfaceMain.cpp, scheduler.cpp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]
2025-07-15 Refacto & fix bug on mtf-01
    [flightCore.cpp, flightCore.hpp, mtf01.hpp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]

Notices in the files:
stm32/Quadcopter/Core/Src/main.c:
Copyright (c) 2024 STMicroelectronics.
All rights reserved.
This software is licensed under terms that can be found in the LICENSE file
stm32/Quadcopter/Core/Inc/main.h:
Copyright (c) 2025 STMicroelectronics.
